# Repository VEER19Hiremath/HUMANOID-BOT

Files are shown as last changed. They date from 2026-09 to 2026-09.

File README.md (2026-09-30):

# HUMANOID-BOT — Hospital Delivery Robot

ROS 2 **Jazzy** workspace for a differential-drive hospital delivery robot: voice room commands, Nav2 navigation, RPLIDAR, and Arduino Mega + matched **BLDC-5015A** wheel drivers (left + right).

Repository: [VEER19Hiremath/HUMANOID-BOT](https://github.com/VEER19Hiremath/HUMANOID-BOT)

> **New here? Read [docs/HANDOVER.md](docs/HANDOVER.md)**: wiring with cable colours, setup (`./setup.sh`), running, calibration, every file explained, troubleshooting. Map of the rooms: [docs/room_map.png](docs/room_map.png).

---

## Hardware

| Part | Notes |
|---|---|
| Raspberry Pi / Ubuntu PC | ROS 2 Jazzy |
| Arduino Mega 2560 | USB to Pi; driver control + wheel-speed feedback |
| BLDC-5015A drivers (×2) | Matched left + right; battery on **DC+/DC−** |
| Brushless hub motors (×2) | Phase U/V/W + Hall plug into each driver |
| Wheel-speed feedback (×2) | One pulse wire per driver into D2/D3 (no separate encoders) |
| RPLIDAR A2M8 | USB (`/dev/lidar` or `ttyUSB0`) |
| Mic + speaker | Voice in / Google TTS out |

Driver switches (both sides):

| Setting | Position |
|---|---|
| **SW2** | **OFF** (speed from Mega AVI, not the knob) |
| **SW1** | Leave as-is (do not change for demo) |
| Round knob **RV** | Fully **counter-clockwise** (min) when using AVI |

Motor battery powers the drivers only (24–50 V on DC+/DC−). **Never** power drivers from Mega 5V. After a latched one-wheel fault: battery **OFF → wait ~10 s → ON**.

Firmware pin map: `arduino/wheelodom.ino`. Cable colors below match the **current robot harness** used in this project.

---

## Wiring (detailed)

Do all control wiring with the **motor battery disconnected**. Connect the battery last.

### 1. Battery → both BLDC-5015A drivers

| Battery | Left driver | Right driver |
|---|---|---|
| + (24–50 V) | **DC+** | **DC+** |
| − | **DC−** | **DC−** |

Check polarity twice. Nothing else on DC+/DC−.

### 2. Motor → driver (each side)

| Motor cable | Driver terminal |
|---|---|
| Three thick phase wires | **U**, **V**, **W** (keep the same order; do not swap for “direction”) |
| Small Hall sensor plug | Hall socket (**REF+**, **REF−**, **HU**, **HV**, **HW**) — push fully in |

Direction is controlled by the Mega **F/R** pin, not by swapping phases.

### 3. Driver control cable → Arduino Mega

Opto commons on the drivers share **+5 V / Vcc** on the driver side; Mega **black** wires are signal **GND** back to the Mega.

| Cable color | Driver signal | Left Mega pin | Right Mega pin | Role |
|---|---|---|---|---|
| **Purple** | **AVI** | **D10** | **D9** | Speed (PWM). Crossed on this harness: left driver ← D10, right ← D9 |
| **Yellow** | **F/R** | **D52** | **D53** | Direction |
| **Red** | **ENBL** | **D22** | **D23** | Run / stop (HIGH = run) |
| **Blue** | **BRK** | **D30** | **D31** | Brake (LOW = released) |
| **Black** | Common / GND | **GND** | **GND** | Signal ground (both drivers) |

> Bench-verified 2026-09-30: **yellow is direction, blue is brake.** An older version of this table had them the other way round. Each wheel then ran one direction only and stalled under PWM in the other, which caused the red driver LED, the "brake stuck" feel and the blown fuses. Always keep **purple → D9/D10** (speed). If purple ever lands on a direction or brake pin, the wheel can run away.

Same table by pin (quick check):

| Mega pin | Goes to |
|---|---|
| D10 | Left AVI (purple) |
| D9 | Right AVI (purple) |
| D52 | Left F/R (yellow) |
| D53 | Right F/R (yellow) |
| D22 | Left ENBL (red) |
| D23 | Right ENBL (red) |
| D30 | Left BRK (blue) |
| D31 | Right BRK (blue) |
| GND | Both driver commons (black) |

### 4. Wheel-speed feedback → Arduino Mega

Each driver's wheel-speed pulse wire goes to the Mega through a **1 kΩ** series resistor. The separate encoders are no longer used (they were never mounted on the wheels). **No 5V** goes to these wires; the Mega's internal pull-up reads them, and the black control wire already shares GND.

| Wire | From | Left Mega pin | Right Mega pin | Role |
|---|---|---|---|---|
| Speed pulse | Driver speed output (or motor Hall line) | **D2** via 1 kΩ | **D3** via 1 kΩ | Wheel pulses (D2/D3 are the only interrupt pins used) |

The firmware uses these pulses for three things:

- **Wheel speed control:** each wheel's speed is measured from the time between its pulses, and a PI loop sets the effort so the wheel turns at the commanded speed whatever its drag. Effort never goes above 32 (the fuse cap).
- **Odometry:** pulses are counted *signed*, in the direction the wheel is driven (a direction change waits until the wheel has coasted down). `base_controller` turns them into `/odom` using the metres-per-pulse in `src/hospital_bringup/config/odometry.yaml`, which it sends to the Mega at connect (`K:<left> <right>`).
- **Stall cut:** a driven wheel that gives no pulse for 0.5 s (after a 1 s start-up grace per wheel) stops both wheels (`STALL HARD STOP`) for a 10 s cool-down, then retries as a fresh start.

`odometry.yaml` holds provisional values until the floor is measured: run `python3 scripts/floor_calibrate.py --tape` once on the floor.

Bench tools (wheels lifted, stack stopped with `./start.sh stop`, Mega auto-detected):

| Script | Purpose |
|---|---|
| `scripts/phase_check.py` | 1.5 s forward + reverse; each wheel must show `OK — runs both ways` |
| `scripts/drive_test.py` | Drives both hubs slowly (3–4 s) with all firmware safeties on; `PASS` needs pulses from both wheels |
| `scripts/bench_matrix.py` | Full BRK / ENBL / F-R / speed case table per wheel (hands off) |
| `scripts/brake_test.py` | Holds raw BRK/ENBL levels (PWM 0) so you can feel which level brakes |
| `scripts/encoder_check.py` | Hand-turn each wheel and read the pulse counts (driver powered) |

### 5. USB / PC

| Device | Port on Pi |
|---|---|
| Arduino Mega | USB → often `/dev/ttyACM0` or `/dev/arduino` |
| RPLIDAR | USB → `/dev/ttyUSB0` or `/dev/lidar` |

Keep Mega and lidar on **separate** USB paths when possible. Motor EMI can drop the Mega (`disabled by hub (EMI?)`) while the lidar keeps spinning.

### 6. Power-up order

1. Mega USB to Pi (sketch boots, `SAFE START READY`, wheels must stay still)  
2. Control + speed-feedback wires as above  
3. Confirm driver LEDs are **off** at idle  
4. Motor battery ON last  
5. `./start.sh`  

### 7. Idle LEDs (healthy)

| Light | Idle expectation |
|---|---|
| Pi / PC power | On |
| Mega ON | Bright |
| Mega TX | May flicker (encoder / status prints) |
| Left / right BLDC LED | **Off** (on = alarm / fault — power-cycle battery) |

Driver manual: [BLDC-5015A / BLDC-5015](https://www.ht-gear.com/uploads/BLDC5015-EN.pdf). Both sides must use the same switch settings (SW2 OFF, RV min).

---

## Quick start

```bash
cd ~/Desktop/veeresh/hospital_robot_ws   # or your clone path
# build once
source /opt/ros/jazzy/setup.bash
colcon build --symlink-install
source install/setup.bash

# run
./start.sh          # base + lidar + map + Nav2 + RViz + voice
./start.sh status
./start.sh stop
```

**Before `./start.sh`:**
1. Mega USB plugged in (`/dev/ttyACM*` or `/dev/arduino`)
2. Lidar USB connected
3. **Place the robot in the MIDDLE of the 30 × 40 ft area, facing along the 40 ft side** (the default map `maps/area_30x40.yaml`; rooms and arrow in `docs/room_map.png`). Its position is counted from that start point, so start it in the same place and direction every time. Scanned maps (`./start.sh map`) use AMCL instead; for those, use RViz **2D Pose Estimate** if the lidar dots don't line up with the walls
4. Prefer **motor battery OFF** until the stack says ready (reduces USB EMI dropouts)
5. Then battery ON to drive

Logs: `run_logs/latest/` in the project, one folder per run (`base.log`, `nav.log`, `voice.log`, …), kept across reboots (newest 30 runs). `/tmp/hospital_robot_logs` points at the latest run. `log/` only holds `colcon build` logs.

### Map a new floor (one command)

The robot only navigates correctly on a map of the floor it is on.

1. Put the robot at the spot that should be **home**, facing the way it will always start (this becomes (0, 0) on the map).
2. Run:
   ```bash
   ./start.sh map
   ```
3. Drive with the keyboard **in the same terminal**: `i` forward, `,` back, `j`/`l` curve left/right, `k` stop. Speed is capped at 0.06 m/s. Go slowly along every wall and into every room. There is **no obstacle stop** while mapping.
4. The map **auto-saves every 30 s** to `maps/floor_map.*`. When it's complete, press **Ctrl+C**. That saves the final map.
5. In RViz pick **Publish Point** and click each spot when the terminal asks: home, room1, room2, … Enter skips a room. This writes `room_config.py` and AMCL's start pose.
6. Everything stops by itself. Put the robot at home and run `./start.sh`. It uses `maps/floor_map.yaml` automatically from now on (`MAP=maps/hospital_map.yaml ./start.sh` for the old lab map).

A previous floor map is kept as `maps/floor_map.bak.*`. To redo only the rooms: run `./start.sh`, then `python3 scripts/pick_rooms.py`.

### Safety while driving

- **Obstacle stop** (lidar, `collision_monitor`): stops for anything 0.27–0.65 m ahead in a 0.60 m wide zone, and drives at 70 % speed for 0.65–1.10 m ahead. `start.sh` prints `Obstacle stop: OK`. If it isn't active, the robot does not drive at all.
- **Microphone watchdog**: **off by default**. In a quiet room a live headset reads the same as a dead one (rms 1–3), so it stopped every trip. `mic_watchdog_s:=15.0` on the voice node turns it on. Because a dead headset can go unnoticed, keep the battery switch or `./start.sh stop` within reach.
- Always keep the motor battery switch, or `./start.sh stop`, within reach.

### Voice examples

After it says listening:

- `go to room one` / `room two` / `room three`. Say numbers as words: the speech model has no digits
- `go home` / `reception`

Speech uses **Google TTS** (needs network); falls back to `espeak` if offline.

---

## Packages (`src/`)

| Package | Role |
|---|---|
| `hospital_bringup` | `real_robot.launch.py`, Nav2 params, localization |
| `hospital_delivery` | Voice delivery node, RViz config, rooms |
| `hospital_description` | URDF / meshes |
| `hospital_world` | Gazebo world (sim) |
| `wheel_odometry` | `base_controller` (Arduino + odom) |
| `rplidar_ros` / `sllidar_ros2` | Lidar drivers |

Demo defaults in `start.sh`:

- `odom_source:=command` (commanded speeds → odom; encoders optional)
- `idle_close_s:=5.0` (closes Arduino serial when parked — less EMI)
- Static `map` → `odom` at start pose `(2.2, 1.6)`
- Lidar obstacle layers disabled in `nav2_params.yaml` when the hospital map ≠ current room (re-enable after remapping)

---

## Arduino firmware

```bash
# Flash Mega (example)
arduino-cli compile -b arduino:avr:mega arduino/wheelodom
arduino-cli upload -b arduino:avr:mega -p /dev/ttyACM0 arduino/wheelodom
```

Sketch: `arduino/wheelodom.ino`. Host tests (simulated wheels with drag, stalls, reversals, timeouts): `arduino/test/run_tests.sh`.

Test tools (stack running, wheels lifted or a clear floor):

| Script | What it checks |
|---|---|
| `scripts/wheel_speed_test.py` | Commanded vs measured speed: straight, slow, arcs, reverse, direction change, stop time |
| `scripts/e2e_test.py [N]` | N random trials through the whole chain (voice command → Nav2 → base → Mega): trips, stop mid-trip, redirects, noise phrases. Results in `run_logs/latest/e2e_results.json` |
| `scripts/plan_check.py` | Plans every room pair (no driving): length, reverses, turn radius, wall clearance |
| `scripts/floor_calibrate.py --tape` | Floor calibration of metres per pulse (drives 1.5 m after Enter) |

Type a command instead of speaking: `ros2 topic pub --once /voice_command std_msgs/String "data: go to room one"`.

---

## Build notes

- Ignore `build/`, `install/`, `log/` (see `.gitignore`)
- Optional: `~/venv` for voice deps; system needs `gTTS`, `vosk`, `sounddevice`, `ffplay` or `mpg123`
- Udev helpers often symlink Mega → `/dev/arduino`, lidar → `/dev/lidar`

---

## Known issues (demo)

| Symptom | Cause | What is in place / what to do |
|---|---|---|
| Wheels fight each other, chassis spins in place | Hubs face opposite ways; same F/R polarity on both sides | Firmware `LEFT_INVERTED=true`, `RIGHT_INVERTED=false`. Opposite-sign wheel commands are blocked in firmware. |
| Fuse blows | A hub stalled under PWM (one direction never ran, see the F/R row below) or a jammed wheel | Fixed root cause (F/R and BRK pins). Also: PWM capped at 30–32, slow ramp up, 300 ms command timeout, opposite-sign commands blocked, `TEST` disabled, and the **stall cut** stops both wheels within ~0.5 s if a wheel gives no speed pulses. Keep one correctly rated fuse per driver. |
| `STALL HARD STOP` in `logs/base.log`, bot stops for 10 s | A wheel gave no speed pulses for 0.5 s while driven: jammed wheel, driver fault (red LED), or a loose D2/D3 feedback wire | Clear the jam, power-cycle the battery if the LED is red, check the feedback wire, then run `scripts/drive_test.py` (wheels lifted). |
| `ENC RIGHT SUSPECT` (or `LEFT`) warning | Only with `ENC_SUSPECT_BYPASS = true`: one feedback line frozen while the other counts | Default is `false` (any frozen wheel = hard stop, which protects the fuses). Turn it on only to keep driving with a known-bad feedback wire. |
| Robot drives in circles; turns go the wrong way | The two **purple speed wires are crossed**: D9 drives the D23/D31/D3 driver and D10 the D22/D30/D2 one (bench 2026-09-30, one wheel at a time). "Slow the left wheel to turn left" slowed the right one, so every turn was reversed. On the floor this looked like an inverted speed signal; with the wheels lifted it's normal (a higher byte is faster) | Fixed in firmware: `L_AVI` = D10, `R_AVI` = D9. `arduino/test/run_tests.sh` checks the pin map. Different drag/speed per wheel is now handled by the firmware's wheel speed control. |
| Robot drives for minutes and never arrives | The floor isn't the mapped room (the map is the 40 × 28 ft lab; the test floor is ~18 ft) | Map the floor you drive on (see **Map a new floor**). |
| Robot doesn't stop or slow for people or objects | Collision monitor and costmap obstacle layers were all disabled | Fixed: `start.sh` runs the collision monitor (see **Safety while driving**). |
| `stop` not heard while driving | The headset mic went silent after the robot spoke (flat signal in `hfp.log`) | The microphone watchdog now stops the robot. Keep the headset close; if it happens, power-cycle the headset link. |
| Robot leaves the map in RViz, or drives somewhere other than where Nav2 thinks | AMCL was disabled. The pose came only from commanded speeds, pinned to a fixed map→odom, so the drift was never corrected | Fixed: `localization.launch.py` runs AMCL (lidar localization), and `start.sh` passes `static_map_odom:=false`. Start the robot at home, or set **2D Pose Estimate** in RViz. |
| Says "Arrived" but the robot is somewhere else (or still stuck near the start) | Pose came from **commanded** speeds (`open_loop_odom`). Log 2026-09-30: the robot stalled 9 s into a trip, the Mega cut drive 9 times, but the pose kept advancing and Nav2 "reached" room1 99 s later | Fixed: odometry comes only from the wheels' signed pulse counts (the command-based mode is removed). A stuck robot fails the goal instead of faking arrival. Calibrate metres per pulse once on the floor (`scripts/floor_calibrate.py --tape`). |
| Nav2 running but bot never moves; `/cmd_vel_nav` has no subscribers | `velocity_smoother` not activated | `velocity_smoother` is in the lifecycle list of `navigation.launch.py`. Check with `ros2 lifecycle get /velocity_smoother`. |
| Goals abort with `Failed to create plan` | The goal or the robot sits inside a wall's inflation | Planner `tolerance: 0.25`. Keep room goals at least 0.6 m from walls in `room_config.py`, then run `scripts/plan_check.py` (plans every room pair without moving the wheels). |
| Path cuts across a wall end in RViz; robot gets stuck in a small room it can't turn around in | Navfn drew sharp corners the arcs-only base can't drive (tightest radius ~0.54 m in `base_controller`); the robot swung wide. And since composition, the **costmaps ignored `nav2_params.yaml`** (Nav2 defaults: 0.1 m radius, no footprint), because the container itself wasn't given the file | Fixed: **Smac Hybrid-A\*** planner (`minimum_turning_radius: 0.60`, Reeds-Shepp = short reverse legs like a 3-point turn), RPP `allow_reversing: true`, the real body footprint 0.54 × 0.50 m, inflation 0.60 m, the params file passed to the container. Goals point along the line from the robot to the room (`goal_yaw`). `scripts/plan_check.py`: 30/30 paths inside the area, body ≥ 0.07 m from every drawn wall. |
| Robot stops for no reason; `collision_monitor: Robot to stop due to invalid source` | On a loaded Pi the odometry TF ran 1–2 s late, so matching each scan to the pose at its exact time failed and the obstacle stop held the robot | `base_shift_correction: false` (uses the latest pose; < 0.1 m error at 0.06 m/s) and replanning every 3 s instead of every 1 s. Close extra programs (browser, VS Code) on the Pi while driving. |
| Robot drives off to room 1 or room 2 by itself | Vosk turned background talk / motor noise into bare words (`one`, `the one`, `a one`, `two`); each was taken as a command (6 times in 10 min on the bench) | Fixed: a room needs a full phrase (`room one`, `go to room one`, `go to the one`, `take me to room four`, `go home`, `reception`). Bare numbers are logged as `Ignoring short phrase` and ignored. `stop` alone still works. |
| `start.sh` hangs during bringup | Lifecycle/DDS calls (map, collision monitor, `/scan`) block | Every check is wrapped in `timeout 2` and only prints a warning. |
| One wheel on straight / both on turn, red LED on driver | Driver latch, F/R, or current brownout | `motorEnable()` toggles ENBL stop→run to clear the latch, and stopping coasts instead of braking. If the red LED stays on, power-cycle the motor battery. |
| Forward: only left turns. Reverse: only right turns. Wheel "tries but can't", red driver LED, fuses blow | Firmware drove the blue wire as direction and the yellow wire as brake, but on the drivers it's the other way round. So each hub ran one way only and stalled under PWM the other way | Fixed in firmware: F/R is on D52/D53 (yellow) and BRK on D30/D31 (blue). `scripts/phase_check.py` must show both wheels `OK — runs both ways`. |
| `start.sh` prints `Obstacle stop: PROBLEM (unconfigured)` and the robot never drives | One of ~10 separate Nav2 processes hung while joining DDS at startup (a different one each time), so Nav2's lifecycle manager waited forever (bench 2026-09-30: 3 of 3 starts) | Fixed: Nav2 runs **composed** (all servers in one `component_container_isolated`, `use_composition:=true`, as in Nav2's own bringup): 4 of 4 starts were healthy. `start.sh` also restarts once if the health check fails, and `stop` cleans stale Fast DDS shared memory (`fastdds shm clean`). |
| Robot swings wide in turns and cuts through walls in RViz / leaves the area | The slowest speed the firmware used (PWM 22) still ran a wheel at ~70 % of cruise, so the inner wheel couldn't slow down: the tightest arc was ~1.5 m wide. The controller's collision check was off, and the `base_controller` map clamp froze the pose at its rectangle edge (goal timeouts) | Fixed: speed maps to effort **in proportion** (`PWM_ZERO_SPEED` 5, cruise 30, min 10; lifted bench: 6 → 9/s … 30 → 56/s), so turn ratios are real. RPP `use_collision_detection: true` stops before a mapped wall. The clamp only applies to open-loop odometry. |
| On the floor: `STALL HARD STOP` every 10 s and the robot never moves again | After a stall's 10 s cool-down the firmware restarted with the **old** motion-start time and stall timers: no start grace, no breakaway kick, and the PWM is up within a millisecond. A loaded wheel that needed a moment to start re-faulted 40 ms later, forever (floor log 2026-09-30) | Fixed: a fault and its cool-down reset `motion_start_ms`, so every retry is a fresh start. Start grace 1000 ms, breakaway 300 ms (was 400 / 150). Obstacle slow zone 70 % speed (50 % = 0.03 m/s was too little effort on the floor). Test: `arduino/test/run_tests.sh`. |
| Tight turns stall every 10 s (`stall/fault` in `base.log`) | Inner-wheel commands of 0.01–0.02 m/s got PWM 0 while still counting as "moving" | Fixed: a moving wheel always gets at least `PWM_START`. |
| Robot detours, loops or reverses "randomly" on the test floor | It planned around the drawn 30 × 40 ft walls, which don't exist on the 18 ft floor | `start.sh` now defaults to **`maps/open_floor.yaml`** (20 × 20 ft test area, no interior walls; rooms 1.3–1.6 m from home, leaving room for forward-only turn-arounds). Rooms are listed in each map (`# room:` lines) and the voice node uses the loaded map's rooms. `MAP=maps/area_30x40.yaml ./start.sh` for the walled area; other floor sizes: `python3 scripts/make_area_map.py open_floor --size W H`. |
| Robot drives in circles / curves although RViz shows a straight path | Odometry scales are provisional: if one wheel's pulses are "shorter", odometry sees a turn that isn't there and Nav2 steers against it | Calibrate once on the floor: `python3 scripts/floor_calibrate.py --tape` (drives 1.5 m after you press Enter, asks for the measured forward/sideways distance, writes `config/odometry.yaml`). |
| Robot ignores things straight ahead; stops for things beside it | The lidar sits inside the body: only ~20 % of beams return and almost none from −40° to +40° (straight ahead). Its open views are behind, the front corners (±45–60°) and the left | No software fix: the obstacle stop **cannot see straight ahead**. Stay at the battery switch. `start.sh` prints `Lidar view: WARNING` while this is so. An opening in the body ahead of the lidar (or mounting it on top) fixes it. The stop zone also watches **behind** the robot while it reverses. |
| Robot sets off or changes destination by itself | Vosk turned noise into phrases like `[unk] gotta toronto` or a bare `toronto` | Phrases with unrecognised sound (`[unk]`) never send or redirect the robot; `toronto` only counts as `go to toronto`. `stop` always works. |
| `stop` acted on ~20 s late, or not at all | The recognizer fell ~20 s behind the headset audio while the Pi was busy driving | It never lags more than ~1 s now (older audio is dropped, logged as `behind: dropped`); cheaper mic level maths; RViz runs at low priority. |
| Robot curves / circles; travels further than the goal; "forgets where to go" | The firmware set a fixed effort per speed, so a wheel with more drag turned slower and the robot curved; the base controller also added guessed motion between pulse reports (double counting) and had several half-wired odometry modes | Rewritten end to end: closed-loop wheel speed in the firmware, pulse-only signed odometry in `base_controller`. Bench: speeds within 3 % of the command, stop in 0.65 s; 100/100 end-to-end trials. |
| `stop` ignored now and then | "stop" cancelled the goal through its handle, which is missing when Nav2's "accepted" reply is lost | "stop" now cancels **all** Nav2 goals (no handle needed), acts the moment it's heard, and zeroes the wheels. 25/25 stop trials: wheels still in ≤ 0.8 s. |
| Robot stops ~0.3 m short of a room | Goal tolerance was 0.30 m | `xy_goal_tolerance: 0.15`: 100 trials arrived within 0.18 m (odometry). |
| Robot spins on the spot ("tornado"), says "Arrived" somewhere else | Wheel DIRECTION CHANGES: the left driver doesn't reliably follow an F/R change made soon after running, so after a reverse leg one wheel kept going backwards. The pulses carry no direction, so odometry saw normal driving | Navigation is **forward-only** (Smac DUBIN planner, no BackUp recovery, no reverse speed), and the firmware switches a driver off while its direction changes (re-key). Direction settings stay `LEFT_INVERTED true`, `RIGHT_INVERTED false` (a straight run from rest goes straight). |
| Robot drives much further and faster than told, crosses the boundary | The drivers give only ~12-13 speed pulses per wheel turn; the guessed 2.5 mm per pulse was ~15x too small | **Measured on the floor (tape at both wheels): 36 mm per pulse, right 0.92 of left** (`config/odometry.yaml`). Cruise 0.15 m/s (real). Re-measure after any wheel, driver or wiring change. Counting both pulse edges was tried and dropped: the right signal adds false edges. |
| Robot creeps into a wall in short stop/go steps | The collision monitor alone sees the few lidar points ahead appear and vanish: each 'continue' let it creep forward | Both costmaps now have a lidar **obstacle layer**: walls and objects stay marked until the lidar sees through them, the planner routes around them and the controller stops before them. |
| "go home" heard as just "home" (ignored) | The mic gate fed the recognizer only audio above the noise floor: the soft start of a phrase and the gaps between words were cut | The last 0.5 s before speech is fed with it, and audio keeps flowing 0.8 s after it. |
| Only one particular headset worked | `hfp_mic.py` had the AirPods' address built in and handled only the mSBC codec | Any paired hands-free headset (connected first, then the others) with mSBC or CVSD; without one, the system mic (USB / wired). New headset: pair it once (`bluetoothctl`: `pair`, `trust`, `connect`). |
| A wheel stalls on slow turns / at the start on the floor | Floor friction stops a slow inner wheel; the PI loop was too slow to free it | Stuck-wheel **kick** (breakaway effort 24 for up to 0.4 s when pulses are missed); start-up push until the first pulse; stall cut waits for 3 pulse gaps. |
| Robot curves on straight lines | Different drag per wheel; small speed differences add up | Per-wheel speed control **plus wheel synchronisation**: the real distances of the two wheels are kept at the commanded ratio (sim: 1 count apart vs 21 without). |
| One wheel gives 0 pulses / won't move (bench test) | Driver latched (red LED) | Battery off 10 s, then on. `scripts/direction_level_test.py` / `brake_level_test.py` test each wheel alone. |
| Mega USB disappears | Motor EMI (`disabled by hub (EMI?)`) | Turn the battery off, reseat the Mega on another USB port, then run `./start.sh` (the script waits up to 90 s for the device). |

Lidar can spin while Mega is missing — they are separate USB devices; start still requires the Arduino.

---

## License

Package licenses are declared in each package’s `package.xml` (mostly Apache-2.0 where specified). Third-party lidar SDK code retains upstream licenses.

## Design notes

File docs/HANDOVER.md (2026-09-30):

# Hospital Delivery Robot — Handover

This document is everything needed to wire, set up, run, calibrate, change and debug the robot. It describes the version on branch **`floor-tested-v1`** (October 2026), which was tested on a 20 × 20 ft open floor.

- Repository: <https://github.com/VEER19Hiremath/HUMANOID-BOT>
- Quick reference and fix history: [`README.md`](../README.md)

---

## Contents

1. [What the robot does](#1-what-the-robot-does)
2. [How it fits together](#2-how-it-fits-together)
3. [Hardware](#3-hardware)
4. [Wiring, with cable colours](#4-wiring-with-cable-colours)
5. [Setting up a computer](#5-setting-up-a-computer)
6. [Running the robot](#6-running-the-robot)
7. [The map and the rooms (RViz)](#7-the-map-and-the-rooms-rviz)
8. [Calibration](#8-calibration)
9. [The code, file by file](#9-the-code-file-by-file)
10. [Tests and test tools](#10-tests-and-test-tools)
11. [Troubleshooting](#11-troubleshooting)
12. [Known limits and next steps](#12-known-limits-and-next-steps)

---

## 1. What the robot does

You say a room ("go to room two") into a Bluetooth headset or a USB microphone. The robot plans a route and drives there on its two hub-motor wheels. It stops at once when you say **"stop"**.

On the way, it stops for people and objects the lidar sees, drives around them when there is room, and waits for them to move when there isn't.

What works (tested on the floor):

- **Voice.** Room commands; "go home"; instant "stop"; redirecting to a new room mid-trip; noise and half-heard phrases are ignored.
- **Driving.** Closed-loop wheel speeds, synchronised wheels, measured odometry, forward-only arcs, stall protection.
- **Navigation.** Rooms 1–3 and home on a 20 × 20 ft map, about 1.2–1.3 m from the centre.
- **Obstacles.** Detour at a safe distance, or wait and continue.

Limits are listed in [section 12](#12-known-limits-and-next-steps). The most important: the robot knows its position **only from its wheels**. On an empty floor the lidar has nothing to localise against, so expect about ±10–25 cm at a room.

---

## 2. How it fits together

```mermaid
flowchart LR
    MIC["Headset / USB mic"] --> HFP["hfp_mic.py<br/>(Bluetooth bridge)"]
    MIC --> PW["PipeWire<br/>(USB / wired mic)"]
    HFP --> VOICE["voice_delivery_node<br/>(Vosk speech → room)"]
    PW --> VOICE
    TXT["/voice_command<br/>(typed commands)"] --> VOICE
    VOICE -- "NavigateToPose goal" --> NAV["Nav2<br/>planner + controller"]
    LIDAR["RPLIDAR A2M8"] -- /scan --> NAV
    LIDAR -- /scan --> CM["collision_monitor<br/>(obstacle stop)"]
    NAV -- /cmd_vel_smoothed --> CM
    CM -- /cmd_vel --> BASE["base_controller<br/>(wheel speeds, odometry)"]
    BASE -- "USB serial: VL/VR, K" --> MEGA["Arduino Mega<br/>wheelodom.ino"]
    MEGA -- "speed, F/R, ENBL, BRK" --> DRV["2 × BLDC-5015A drivers"]
    DRV --> MOT["2 × hub motors"]
    DRV -- "speed pulses D2/D3" --> MEGA
    MEGA -- "pulse counts L:/R:" --> BASE
    BASE -- "/odom + TF" --> NAV
    NAV --> RVIZ["RViz<br/>(map, rooms, path)"]
```

In words:

1. **Speech to goal.** `voice_delivery_node` turns a recognised phrase into a room. It sends Nav2 a goal at that room's position, taken from the map file.
2. **Planning.** Nav2's planner (Smac Hybrid-A\*, forward-only) plans a route made of arcs the robot can actually drive.
3. **Following.** The controller (Regulated Pure Pursuit) follows that route and outputs a body speed and turn rate.
4. **Safety gate.** The collision monitor passes those commands on, or replaces them with a stop or a slowdown when the lidar sees something close ahead.
5. **Wheel speeds.** `base_controller` turns body speed and turn rate into left and right wheel speeds. It sends them to the Mega 50 times a second.
6. **Motor control.** The Mega runs a speed controller for each wheel. It sets each driver's speed input (PWM), direction, enable and brake, using the wheel-speed pulses from the drivers.
7. **Odometry.** The Mega reports pulse counts every 50 ms. `base_controller` turns them into the robot's position (`/odom` and the `odom → base_footprint` transform).
8. **Map frame.** With the drawn map, `map → odom` is fixed at the start spot ("home"). The robot's position is therefore pure wheel odometry from where it was started.

---

## 3. Hardware

| Part | Notes |
|---|---|
| Raspberry Pi (Ubuntu 24.04, ROS 2 Jazzy) | Runs everything except motor control |
| Arduino Mega 2560 | USB to the Pi; motor drivers and wheel-speed feedback |
| 2 × BLDC-5015A motor drivers | Left and right; powered from the motor battery on **DC+ / DC−** |
| 2 × brushless 6-inch hub motors | Three phase wires and a Hall-sensor plug into each driver |
| RPLIDAR A2M8 | USB; 360° at 10 Hz, range 12 m |
| Bluetooth headset or USB microphone | Voice input; any paired hands-free headset works |
| Motor battery (24–50 V) | Drivers only, with one fuse per driver |
| Robot body | **2 ft × 1.5 ft** (0.61 × 0.46 m), centred on the wheel axle; wheels 0.43 m apart |

Driver switches, the same on **both** drivers:

| Setting | Position |
|---|---|
| **SW2** | **OFF**: speed comes from the Mega (AVI input), not the knob |
| **SW1** | Leave as it is |
| Round knob **RV** | Fully **anticlockwise** |

Driver manual: [BLDC-5015A](https://www.ht-gear.com/uploads/BLDC5015-EN.pdf).

---

## 4. Wiring, with cable colours

> **Do all control wiring with the motor battery disconnected. Connect the battery last.** Never power the drivers from the Mega's 5 V.

### 4.1 Battery → drivers

| Battery | Left driver | Right driver |
|---|---|---|
| + (24–50 V), through a fuse | **DC+** | **DC+** |
| − | **DC−** | **DC−** |

Check polarity twice.

### 4.2 Motor → driver (each side)

| Motor cable | Driver terminal |
|---|---|
| Three thick phase wires | **U, V, W**: keep the original order. Do **not** swap them to change direction; the Mega's F/R line does that. |
| Small Hall-sensor plug | Hall socket (REF+, REF−, HU, HV, HW), pushed fully in |

### 4.3 Driver control cable → Mega

| Cable colour | Driver signal | **Left** → Mega | **Right** → Mega | What it does |
|---|---|---|---|---|
| 🟣 **Purple** | AVI | **D10** | **D9** | Speed (PWM). The two purple wires are **crossed** on this harness: the left driver is on D10, the right on D9. |
| 🟡 **Yellow** | F/R | **D52** | **D53** | Direction |
| 🔴 **Red** | ENBL | **D22** | **D23** | Run / stop (HIGH = run) |
| 🔵 **Blue** | BRK | **D30** | **D31** | Brake (LOW = released) |
| ⚫ **Black** | COM / GND | **GND** | **GND** | Signal ground, shared by both drivers |

By pin, for a quick check:

| Mega pin | Goes to |
|---|---|
| D2 | Left speed pulse (through 1 kΩ) |
| D3 | Right speed pulse (through 1 kΩ) |
| D9 | Right AVI (purple) |
| D10 | Left AVI (purple) |
| D22 / D23 | Left / right ENBL (red) |
| D30 / D31 | Left / right BRK (blue) |
| D52 / D53 | Left / right F/R (yellow) |
| GND | Both driver commons (black) |

> **Yellow is direction, blue is brake.** With them the other way round, each wheel ran in one direction only and stalled in the other: red driver LED, blown fuses. **Purple must only ever go to D9 / D10.** A speed wire on a direction or brake pin can make a wheel run away.

### 4.4 Wheel-speed feedback → Mega

| Wire | From | Left | Right |
|---|---|---|---|
| Speed pulse | Driver speed output | **D2** through **1 kΩ** | **D3** through **1 kΩ** |

- No 5 V goes on these wires: the Mega's internal pull-up reads them, and the black wire provides the shared ground.
- The drivers give about **12–13 pulses per wheel turn**, which is **36 mm of travel per pulse**.
- Keep these wires away from the motor phase wires. The **right** signal picks up false pulses (see [section 12](#12-known-limits-and-next-steps)).

### 4.5 USB

| Device | Port |
|---|---|
| Arduino Mega | `/dev/serial/by-id/usb-Arduino*` (found automatically) |
| RPLIDAR | `/dev/serial/by-id/usb-Silicon_Labs*` (found automatically) |

Use separate USB ports. Motor noise can disconnect the Mega; if so, power off, then reseat it on another port.

### 4.6 Power-up order and healthy lights

1. Mega USB to the Pi. It prints `SAFE START READY` and the wheels stay still.
2. Control and speed wires connected.
3. Driver LEDs are **off** at idle.
4. Motor battery **on**.
5. `./start.sh`.

**A red driver LED means the driver has latched a fault.** Turn the battery **off, wait 10 s, turn it on again**.

---

## 5. Setting up a computer

On a fresh Raspberry Pi with Ubuntu 24.04:

```bash
git clone https://github.com/VEER19Hiremath/HUMANOID-BOT.git ~/Desktop/veeresh
cd ~/Desktop/veeresh
git checkout floor-tested-v1
./setup.sh --test          # install everything, build, run the unit tests
./setup.sh --flash         # with the Mega plugged in: put the firmware on it
```

[`setup.sh`](../setup.sh) does the following (each step is skipped if already done):

| Step | What |
|---|---|
| 1 | ROS 2 Jazzy (if missing) and the ROS packages the robot uses: Nav2, the Smac planner, collision monitor, slam_toolbox, robot_state_publisher, teleop, RViz |
| 2 | System packages: pyserial, numpy, scipy, matplotlib; PipeWire, ALSA, BlueZ and the SBC codec (headset audio) |
| 3 | `~/venv` with the speech packages from [`requirements.txt`](../requirements.txt) (Vosk) |
| 4 | The Vosk speech model in `~/models/vosk-model-small-en-us-0.15` |
| 5 | `arduino-cli` and the AVR core in `.tools/` (used to flash the Mega) |
| 6 | Adds you to the `dialout` group for serial-port access. Log out and back in once afterwards. |
| 7 | `colcon build` of the workspace |

### Headset (once per headset)

```bash
bluetoothctl
  scan on              # put the headset in pairing mode; note its address
  pair  XX:XX:XX:XX:XX:XX
  trust XX:XX:XX:XX:XX:XX
  connect XX:XX:XX:XX:XX:XX
  exit
```

After pairing once, the robot picks the headset up by itself. It takes the connected headset first, then tries every paired hands-free headset. A USB microphone also works, with nothing to configure.

**Headsets connect to one device at a time.** Turn off Bluetooth on your phone before starting the robot.

---

## 6. Running the robot

### Start

1. Put the robot **in the middle of the area**, facing the direction you want "forward" (room1 is straight ahead).
2. Battery on.
3. Run:

```bash
cd ~/Desktop/veeresh
./start.sh
```

Wait about 2 minutes for this:

```text
Mega: OK
Lidar:          OK  (10 scans/s)
Odometry:       OK  (20 msgs/s)
Localization:   OK  (map frame published)
Map:            OK  (received)
Obstacle stop:  OK  (active)
Lidar view:     NOTE (… % of beams return …)   ← normal on an open floor
Ready: say 'go to room one' (rooms of the map: see docs/room_map.png), 'go home' or 'stop'.
```

If a check says PROBLEM, `start.sh` restarts everything once by itself. If it still fails: `./start.sh stop`, then `./start.sh` again.

**The spot where you start is "home".** The robot's position is measured from there, so always start at the same place, facing the same way.

### Voice commands

| Say | Robot |
|---|---|
| "go to room one" / "room one" / "go to one" | Drives to room1 (same pattern for two and three) |
| "go home" / "go to home" / "reception" | Drives back to the start spot |
| "stop" | Stops at once and cancels the trip |
| A new room during a trip | Changes destination |

- Speak close to the mic, and use full phrases.
- A bare "one" or "home" is ignored on purpose: background noise produces those.
- Unsure recognitions are logged as `Ignoring unsure phrase …` and do nothing.
- The Pi has no speaker, so the robot doesn't talk back. Its replies ("Going to room 2", "Arrived") appear in the voice log. Plug in a speaker and they're spoken, if Google TTS is installed.

**Typed commands** go through exactly the same path as speech:

```bash
source /opt/ros/jazzy/setup.bash
ros2 topic pub --once /voice_command std_msgs/String "data: go to room two"
```

### Obstacles

| Situation | Behaviour |
|---|---|
| Something 0.70–1.10 m ahead | Slows to 70 % |
| Something 0.32–0.70 m ahead (0.32–0.65 m behind when reversing) | Stops |
| A way round exists | Replans around it, keeping a safe distance (0.6 m inflation), and continues |
| No way round | Waits; tries again every few seconds for about 2–3 minutes, then gives up ("Could not reach") |
| Obstacle goes away | Continues to the room by itself |

### Stop and logs

```bash
./start.sh stop           # stop everything
./start.sh status         # what is running
```

**Emergency stop:** say "stop", or switch the motor battery off.

Every start writes a new log folder: `run_logs/<date>_<time>_start/`. `run_logs/latest` always points at the newest; the last 30 runs are kept.

| Log | Contains |
|---|---|
| `voice.log` | What was heard, what was ignored and why, goals sent, arrivals |
| `nav.log` | Nav2: plans, obstacle stops, failures |
| `base.log` | Mega status every second (effort, pulses, measured and target speed), stalls; lidar driver |
| `hfp.log` | Bluetooth headset bridge |
| `map.log` | Map server |

---

## 7. The map and the rooms (RViz)

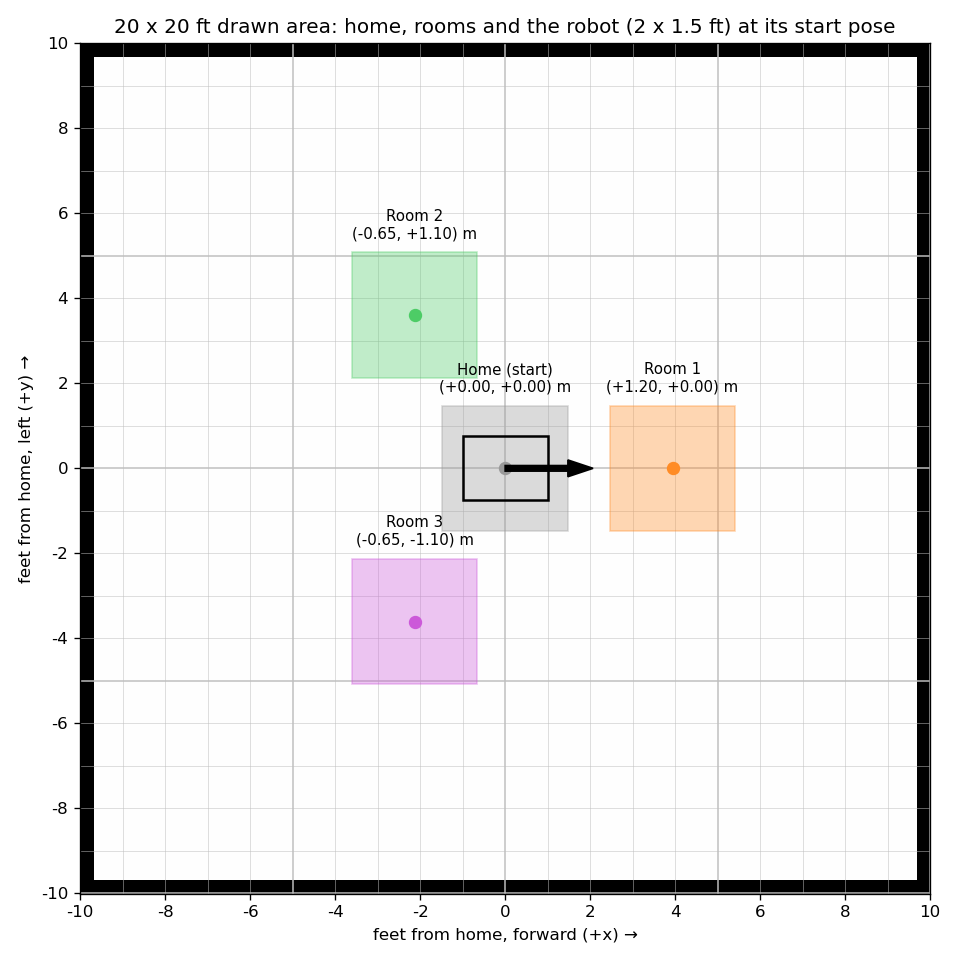
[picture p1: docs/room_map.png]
Map with home and rooms


The current map is **`maps/open_floor.yaml`**: a 20 × 20 ft empty square, with home in the middle.

| Room | Position (x forward, y left), from home | Where |
|---|---|---|
| home | (0, 0) | Start spot, facing +x |
| room1 | (1.20, 0.00) m, about 4 ft | Straight ahead |
| room2 | (−0.65, +1.10) m | Behind, left |
| room3 | (−0.65, −1.10) m | Behind, right |

**What RViz shows** (it opens with `./start.sh`):

- the map;
- coloured **room zones with names** (the room being driven to is highlighted);
- the **planned path** in green;
- the **obstacle-stop zone** in red;
- lidar points;
- the robot model.

**Why the rooms are so close in.** The robot drives forward only, and turns with a radius of at least 0.5 m. To turn round it needs about 1.5 m of floor beyond a room. Rooms further out sent the robot within 0.5 m of an edge, where it got stuck.

### Changing the rooms or the area

1. Edit `MAPS['open_floor']` in [`scripts/make_area_map.py`](../scripts/make_area_map.py): `size_ft` and `rooms` (in metres, x forward, y left).
2. Regenerate the map, the picture, and check every trip without driving:

```bash
python3 scripts/make_area_map.py open_floor     # writes maps/open_floor.pgm/.yaml
python3 scripts/render_map.py                   # writes docs/room_map.png
./start.sh                                      # then, in another terminal:
python3 scripts/plan_check.py                   # plans every room pair (no driving)
```

`plan_check.py` must report `0 problem path(s)`. Each path's `wall gap` should be 0.4 m or more.

The rooms live **in the map file** as `# room: name x y` lines. The voice node and RViz both read them from there. `room_config.py` only holds the spoken names and a fallback.

### Scanning a real room instead (optional)

In a room with walls and furniture, a scanned map lets the lidar correct the position continuously. That is more accurate than wheel odometry alone.

```bash
./start.sh map
```

Drive slowly along every wall with the keyboard. The map auto-saves every 30 s. Press Ctrl+C when done, then click the rooms in RViz when asked.

`start.sh` then uses `maps/floor_map.yaml` with lidar localisation (AMCL). This is **not useful on an empty floor**: there is nothing for the lidar to see.

---

## 8. Calibration

### Wheel distance (do it after changing a wheel, driver or wiring)

The robot's sense of distance comes from `src/hospital_bringup/config/odometry.yaml`:

```yaml
distance_per_pulse: 0.0360        # metres per LEFT wheel pulse
right_encoder_multiplier: 0.92    # right pulse length / left
```

To re-measure:

1. `./start.sh`, with about 2 m clear ahead.
2. In a second terminal, run `./start.sh calibrate`.
3. Tape the floor at both wheel hubs and press Enter. The robot drives 1.5 m (by its own count).
4. Tape the hubs again. Type how far the midpoint moved **forward** and **sideways** (cm, left is +).
5. It writes the new values. Run `./start.sh stop; ./start.sh`.

By hand instead: drive 1 m by its count, measure **each wheel's** travel, and set:

- `distance_per_pulse = (left wheel cm / 100) / left pulses`;
- `right_encoder_multiplier = (right cm / left cm) × (left pulses / right pulses)`.

The pulse counts are in `base.log` (`L=… R=…`).

### Wheel direction (after any motor or driver rewiring)

```bash
./start.sh stop
python3 scripts/wheel_direction_test.py     # each wheel alone at its forward level (read from the firmware), 3 s
```

**Each wheel must roll forward.** If one rolls backward, flip `LEFT_INVERTED` or `RIGHT_INVERTED` in `arduino/wheelodom.ino` and reflash (`./setup.sh --flash`).

Current, verified setting: `LEFT_INVERTED true`, `RIGHT_INVERTED false`. A straight run from rest must go straight.

---

## 9. The code, file by file

### 9.1 Overview

| Path | Language | Role |
|---|---|---|
| `arduino/wheelodom.ino` | Arduino C++ | Motor control on the Mega |
| `arduino/test/` | C++ | Host tests for the firmware (simulated wheels) |
| `src/wheel_odometry/` | Python (ROS 2) | `base_controller`: Mega link, wheel speeds, odometry |
| `src/hospital_delivery/` | Python (ROS 2) | Voice control, rooms, RViz room markers, RViz config |
| `src/hospital_bringup/` | Launch / YAML | Starting everything, Nav2 settings, odometry calibration, behaviour tree |
| `src/hospital_description/` | URDF | Robot model (frames: base_footprint, base_link, laser, wheels) |
| `src/rplidar_ros/` | C++ | Lidar driver (vendor package, with startup fallbacks added) |
| `src/hospital_world/`, `src/sllidar_ros2/` | | Simulation world and a spare lidar driver. **Not used** on the real robot. |
| `maps/` | | `open_floor` (current), `area_30x40` (old drawn area); a scan becomes `floor_map` |
| `scripts/` | Python | Setup helpers, calibration, tests, map tools |
| `start.sh`, `setup.sh` | Bash | Run the robot / install everything |

### 9.2 `arduino/wheelodom.ino`: motor control on the Mega

Runs on its own, independent of ROS. If the Pi stops talking for 300 ms, the motors stop.

**Serial protocol (115200 baud):**

| Pi → Mega | Meaning |
|---|---|
| `VL:<m/s> VR:<m/s>` | Wheel speeds. Must repeat within 300 ms. |
| `K:<left> <right>` | Metres per pulse for each wheel. Sent by `base_controller` at connect. |
| `PINS …` / `PINS OFF` | Bench mode: raw pin levels on one wheel. Stops by itself 1.5 s after the last command. |

| Mega → Pi | Meaning |
|---|---|
| `SAFE START READY` | Booted, motors off |
| `L:<count> R:<count>` | Signed pulse counts, every 50 ms |
| `S: pwmL=… pwmR=… … spL=… spR=… tgL=… tgR=…` | While driving: effort, measured (`sp`) and target (`tg`) wheel speed in pulses/s |
| `STALL HARD STOP` | A driven wheel stopped turning; both cut for 10 s |
| `K OK <l> <r>` | Pulse sizes accepted |

**How it drives a wheel** (`controlWheel()`, every 20 ms):

- **Speed measurement.** Each speed pulse fires an interrupt (`countPulse`). The interrupt counts the pulse (signed: + forward, − reverse) and records the time since the previous pulse. Speed is 1 / pulse interval. Pulses closer than 5 ms are ignored as noise. Only rising edges are counted, because the right wheel's falling edges carry false pulses.
- **PI speed controller.**
  - Feed-forward from a measured effort curve, plus proportional and integral terms on the speed error (`KP 0.25`, `KI 1.0`).
  - A wheel with more drag automatically gets more effort.
  - Effort is clamped to **6–32**. **32 is the fuse cap**: never raise it; higher stall currents blew fuses.
- **Start push.** Until a wheel's first pulse (up to 0.6 s), its effort is at least **24**, to break floor friction.
- **Stuck-wheel kick.** If a driving wheel misses its pulses (1.5 expected intervals, at least 0.3 s), it gets effort 24 for up to 0.4 s.
- **Wheel synchronisation** (`synchronise()`).
  - While both wheels drive the same way, the real distance each has covered since the command changed must keep the commanded ratio (1 on a straight line).
  - The behind wheel is sped up and the other slowed, by up to 0.03 m/s.
  - In simulation, a wheel at its power limit ended 1 count from the other with sync, 21 without.
- **Direction change.** The wheel coasts down (up to 1.5 s), then its driver is **switched off**, the F/R line is set, and the driver is switched on again 0.3 s later. The left driver doesn't reliably follow a direction change while enabled.
- **Stall cut** (`wheelFrozen()`, fuse protection).
  - Trigger: a driven wheel with effort ≥ 12 and no pulse for 3 expected intervals (at least 0.5 s), after a 1 s start-up grace for that wheel.
  - Action: **both** wheels stop for 10 s, then the Mega retries as a fresh start.
- **Safety rules.**
  - The wheels are never driven in opposite directions.
  - A one-wheel command becomes an arc (the other wheel at 45 %).
  - No command for 300 ms means motors off.
  - The brakes are always released (stopping is a coast).

**Key settings at the top of the file:**

- pin numbers;
- `LEFT_INVERTED` / `RIGHT_INVERTED` (direction polarity);
- `PWM_MAX` (fuse cap);
- the speed-control gains;
- stall timings.

**Flash:** `./setup.sh --flash` (stop the robot first: `./start.sh stop`).

**Tests:** `arduino/test/run_tests.sh` compiles the sketch against a mock Arduino (`Arduino.h`). It runs 42 tests (`test_firmware.cpp`) with simulated wheels that have load, lag, friction, jams and noise: speed tracking, drag compensation, arcs, sync, reversals, re-key, stalls, kicks, timeouts, bench mode, the pin map.

### 9.3 `src/wheel_odometry/wheel_odometry/base_controller.py`: Mega link and odometry

A ROS 2 node, started by `real_robot.launch.py`:

- **`/cmd_vel` → wheel speeds** (`wheel_speeds()`).
  - Turn rate is limited so the inner wheel keeps at least ~36 % of the outer (radius ≥ 0.46 m).
  - Turning on the spot becomes a forward arc at 0.08 m/s.
  - Wheel speeds are capped at **0.15 m/s**, keeping the left/right ratio.
  - The wheels are never driven in opposite directions.
- **Easing** (`ease()`). Wheel speeds change at 0.10 m/s² up and 0.30 m/s² down.
- **Serial link.**
  - Opens the Mega without resetting it (DTR held low).
  - Waits for it to boot, then sends `K:` (pulse sizes from `odometry.yaml`).
  - Sends `VL/VR` at 50 Hz.
  - Reconnects by itself if the USB drops, and re-sends `K:` if the Mega restarts.
- **Odometry** (`_on_counts()`, `integrate()`).
  - Signed counts × metres per pulse give each wheel's distance.
  - The exact arc update gives the new pose.
  - Published as `/odom` and the `odom → base_footprint` transform, with measured speed.
  - No guessing between reports.
- **Logs.** The Mega status line once a second; stall messages.

Parameters (from `src/hospital_bringup/config/odometry.yaml` and the launch file): `arduino_port`, `wheel_base` (0.4318 m), `distance_per_pulse`, `right_encoder_multiplier`.

Tests: `src/wheel_odometry/test/test_base_controller_math.py` (9 tests: arc limits, no opposite wheels, easing, arc odometry).

`teleop_keyboard.py` is a simple keyboard driver. `./start.sh map` uses the standard `teleop_twist_keyboard` instead.

### 9.4 `src/hospital_delivery/hospital_delivery/voice_delivery_node.py`: voice control

**Microphone** (`_listen_loop()`):

- **Bluetooth headset.** Audio comes from `scripts/hfp_mic.py` through `/tmp/hospital_hfp_mic.sock`. It's used while the bridge reports audio flowing (`/tmp/hospital_hfp_mic.up`).
- **Otherwise the system microphone** through PipeWire (`arecord`). Switches automatically both ways.
- If audio falls more than 1 s behind (busy Pi), old audio is dropped, so "stop" is never late.

**Speech gate** (`_consume_audio()`):

- Only audio above the room's noise floor is fed to the recognizer.
- **0.5 s before** speech starts and **0.8 s after** it drops are fed too, so a phrase's soft start and its pauses aren't cut.

**Recognizer** (`_new_recognizer()`):

- Vosk, limited to the command phrases of the rooms on the loaded map (`ROOM_ALIASES`).
- Reports per-word confidence.

**Accepting a command** (`_queue_command()`, `_handle_command()`):

- **"stop"** acts on the first partial guess; a false stop is harmless. It cancels **all** Nav2 goals through the action's cancel service (`stop_robot()`), even if the goal handle was lost, and publishes zero speed.
- **Room commands** need a **finished** phrase. Every word must have confidence **≥ 0.4** (parameter `min_confidence`), and the phrase must be complete ("room one", "go to room one", "go home"; not a bare "one" or "home").
- Phrases with unrecognised sound (`[unk]`) are ignored, unless "room \<n\>" or "go home" was heard clearly.
- The same phrase within 3 s is ignored.

**Goal** (`navigate_to_room()`):

- Position comes from the map file's `# room:` lines.
- Heading is the bearing from the robot's current position, so it arrives driving straight in.
- A new goal replaces the old one (Nav2 preempts).
- `_on_nav_result()` logs "Arrived at …", "ABORTED" or "cancelled".

**Other details:**

- `/voice_command` (`std_msgs/String`) feeds typed text into the same path.
- Speech output uses Google TTS, then espeak, if installed.

Parameters: `map_yaml` (set by `start.sh`), `min_confidence` (0.4), `mic_watchdog_s` (0 = off).

### 9.5 Other `hospital_delivery` files

| File | What it does |
|---|---|
| `room_config.py` | `ROOM_ALIASES`: the spoken forms of each room. `rooms_from_map()`: reads `# room:` lines. `goal_yaw()`: heading towards a room. `room_heading()`: alternative "face the centre" heading, currently unused. `ROOM_COORDS`: fallback rooms. |
| `room_markers.py` | Publishes `/room_markers` for RViz: a zone, pin and name per room; highlights the room at the end of the planned path. |
| `rviz/hospital_nav.rviz` | RViz layout: map, scan, robot model, TF, rooms, planned path, stop zone |

### 9.6 `scripts/hfp_mic.py`: Bluetooth headset bridge

Acts as the "phone" (hands-free audio gateway) for any paired headset. PipeWire's own handling made headsets drop the call link before any audio flowed.

- Picks the connected hands-free headset, or tries each paired one; the last one that worked goes first (`~/.hospital_headset`).
- Opens the control link (RFCOMM) and answers the headset's AT commands.
- Opens the audio link (SCO) with **mSBC** (wideband, decoded with libsbc) or **CVSD** (narrowband).
- Publishes 16 kHz audio on the socket, and creates `/tmp/hospital_hfp_mic.up` while audio flows.

### 9.7 `src/hospital_bringup/`: launch files and settings

| File | What it does |
|---|---|
| `launch/real_robot.launch.py` | Robot model (robot_state_publisher), fixed `map → odom` at home (drawn maps), `base_controller` with `odometry.yaml`, lidar driver |
| `launch/localization.launch.py` | Map server, plus AMCL for scanned maps |
| `launch/navigation.launch.py` | All Nav2 servers in **one** process (`component_container_isolated`), managed by a lifecycle manager. Separate processes hung at startup on this Pi. |
| `launch/full_system.launch.py` | Old combined launch, **not used** |
| `config/odometry.yaml` | Wheel calibration ([section 8](#8-calibration)) |
| `config/nav2_params.yaml` | All Nav2 settings, summarised below |
| `config/slam_params.yaml` | slam_toolbox settings for `./start.sh map` |
| `behavior_trees/navigate_to_pose.xml` | Plan → follow → on failure: clear costmaps / wait, retry (30 times, ~2–3 min). Replans every 3 s. No back-up or spin recovery. |

**`nav2_params.yaml`, the important settings:**

| Section | Setting | Value | Why |
|---|---|---|---|
| `planner_server` | `SmacPlannerHybrid`, `DUBIN` | Forward-only arcs | Reversing changes wheel direction, which the left driver doesn't reliably follow |
| | `minimum_turning_radius` | 0.50 m | `base_controller` allows ~0.46 m |
| `controller_server` | RPP `desired_linear_vel` | 0.15 m/s | Real speed (calibrated) |
| | `allow_reversing` | false | Forward-only |
| | `xy_goal_tolerance` | 0.25 m | Tighter tolerances made the robot loop round for another try |
| | `failure_tolerance` | 3 s | Brief blockage doesn't abort |
| | `use_collision_detection` | true | Won't drive a path into an obstacle |
| `velocity_smoother` | `min_velocity` | 0 | Navigation never reverses |
| Both costmaps | `footprint` | ±0.31 × ±0.23 m | The 2 × 1.5 ft body |
| | `inflation_radius` | 0.60 m | Safe distance from walls and obstacles |
| | `obstacle_layer` | lidar, `inf_is_valid: true` | Detours around live obstacles; marks clear when they leave |
| `collision_monitor` | `PolygonStop` | 0.32–0.70 m ahead / 0.32–0.65 m behind | Hard stop |
| | `PolygonSlow` | 0.70–1.10 m ahead, ×0.7 | Slowdown |
| | `base_shift_correction` | false | Late TF on a busy Pi made it stop for "invalid source" |

### 9.8 `start.sh`

| Command | What it does |
|---|---|
| `./start.sh` | Stops leftovers. Starts the robot (base, lidar, map, Nav2, RViz, headset bridge, voice, room markers). Checks health and restarts once if needed. |
| `./start.sh stop` | Stops everything (force-kills stuck nodes, clears stale shared memory) |
| `./start.sh status` | Lists running parts |
| `./start.sh map` | Scans a new map with keyboard driving, then lets you pick rooms |
| `./start.sh savemap [name]` | Saves the map being scanned |
| `./start.sh calibrate` | Wheel-distance calibration ([section 8](#8-calibration)) |

The map is chosen in this order:

1. `maps/floor_map.yaml` (if a scan exists);
2. `maps/open_floor.yaml`;
3. `maps/area_30x40.yaml`.

Override with `MAP=maps/x.yaml ./start.sh`.

---

## 10. Tests and test tools

**Without the robot moving:**

| Command | Checks |
|---|---|
| `arduino/test/run_tests.sh` | 42 firmware tests (simulated wheels) |
| `cd src/wheel_odometry && python3 -m pytest -q test/test_base_controller_math.py` | 9 base-controller tests |
| `python3 scripts/plan_check.py` | Plans every room pair: length, reverses, turn radius, distance to walls |
| `python3 scripts/health_check.py` | The startup checks, on demand |

**Wheels lifted, or a clear floor** (these move the robot; stay at the battery switch):

| Command | Checks |
|---|---|
| `python3 scripts/wheel_speed_test.py` | Commanded vs measured speed: straight, slow, arcs, reverse, stop time |
| `python3 scripts/e2e_test.py [N]` | N random trials through the whole chain (typed commands → Nav2 → wheels): trips, stops, redirects, noise phrases |
| `python3 scripts/floor_tour.py` | Every room from home and back, with outcome, time, stops and stalls per leg; stops at the area boundary |

**Bench tools** (stack stopped with `./start.sh stop`):

| Command | Checks |
|---|---|
| `wheel_direction_test.py` | Each wheel alone at its "forward" level: must roll forward |
| `direction_level_test.py` | Each wheel with F/R LOW and HIGH: must turn both ways |
| `brake_level_test.py` | Each wheel with BRK LOW and HIGH: LOW must release |
| `drive_test.py`, `phase_check.py`, `bench_matrix.py`, `encoder_check.py`, `brake_test.py`, `avi_sweep.py` | Older bench checks (see the README) |
| `direction_check.py`, `pivot_check.py` | Lidar-based direction checks. Need a room with walls in range. |

**Map tools:** `make_area_map.py` (draw a map with rooms), `render_map.py` (map picture), `pick_rooms.py` (click rooms on a scanned map).

---

## 11. Troubleshooting

| Symptom | Likely cause | What to do |
|---|---|---|
| Robot doesn't move; `base.log` shows `STALL HARD STOP` and `L=0` or `R=0` | A driver is latched (red LED) or unpowered, or a speed wire is loose | Battery off for 10 s, then on. Check fuses, LEDs, and the D2/D3 wires. Use `brake_level_test.py` to test each wheel alone. |
| Robot spins on the spot | A wheel runs backwards | `wheel_direction_test.py`. Flip the `*_INVERTED` setting for that wheel and reflash. |
| Drives too far or too short | Calibration off | [Section 8](#8-calibration) |
| Curves on a straight line | Right signal noise or calibration | Check the D3 wire; re-measure both wheels |
| Voice: nothing happens | No mic: `voice.log` says "No microphone yet" | Connect the headset (turn off phone Bluetooth), or plug in a USB mic |
| Voice: "Ignoring unsure phrase" | Unclear speech or noise | Speak closer and clearly. Lower `min_confidence` if needed (0.3–0.4). |
| Voice: "Ignoring short phrase" | Bare "one" / "home" | Say "room one" / "go home" |
| Goal fails with "no valid path" | The robot is near an edge, or something blocks the room | Move it back to home and restart. Clear the area. |
| Robot keeps stopping | Something within 0.7 m ahead, often the person watching | Stand outside the area |
| `Obstacle stop: PROBLEM` at start | Nav2 startup hang | `start.sh` restarts once by itself; otherwise run `./start.sh stop; ./start.sh` |
| `Lidar view: NOTE` | Nothing within 12 m (open floor) | Normal. If there *are* things around, check the lidar is uncovered and level. |
| Mega disappears from USB | Motor noise | Battery off, reseat the Mega on another USB port, `./start.sh` |
| Fuse blows | A wheel stalled under effort | Find the jam. Never raise `PWM_MAX` (32). |

---

## 12. Known limits and next steps

| Limit | Detail | Next step |
|---|---|---|
| **Position from the wheels only** | On an empty floor the lidar sees nothing within 12 m, so there's no correction. Expect ±10–25 cm at a room, growing with distance driven. | Put landmarks (boxes, panels) around the area, or work in a room with walls, and scan it with `./start.sh map`. AMCL then corrects the position continuously. |
| **Coarse wheel pulses** | ~12–13 pulses per wheel turn = 36 mm steps; a one-pulse difference is about 5° of heading | Wheel encoders with more counts per turn would improve odometry and low-speed control a lot |
| **Right speed signal noise** | False pulses on its falling edges (hence rising edges only) | Check the D3 wire: shielded or twisted with ground, away from the phase wires; add a small capacitor to ground |
| **Left driver** | Sometimes latches (wheel held, 0 pulses); doesn't follow direction changes made soon after running | Battery off/on clears it. If it keeps happening, check that driver's wiring and fuse, or replace it. |
| **Forward-only driving** | Can't back away from a wall; rooms must stay ~1.2–1.3 m from the centre in a 20 × 20 ft area | Once the left driver is fixed, reversing could be re-enabled (Reeds-Shepp planner, BackUp recovery). The firmware already handles direction changes safely. |
| **No speaker** | Replies only in the log | USB speaker or sound card |
| **Speech model** | Small Vosk model; headset audio is narrowband | A larger Vosk model or a better microphone improves recognition |

### Versions

| Name | What |
|---|---|
| Branch `floor-tested-v1` | This version (drive, voice, obstacles) |
| Tag `floor-tested-v1` | The first floor-tested drive and voice commit |
| `main` | The older version, before this work |

To restore a version: `git checkout floor-tested-v1`.

Always re-run `./setup.sh --flash` after checking out a version with different firmware.

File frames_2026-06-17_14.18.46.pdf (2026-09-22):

view_frames Result

Recorded at time: 1781686126.4121716

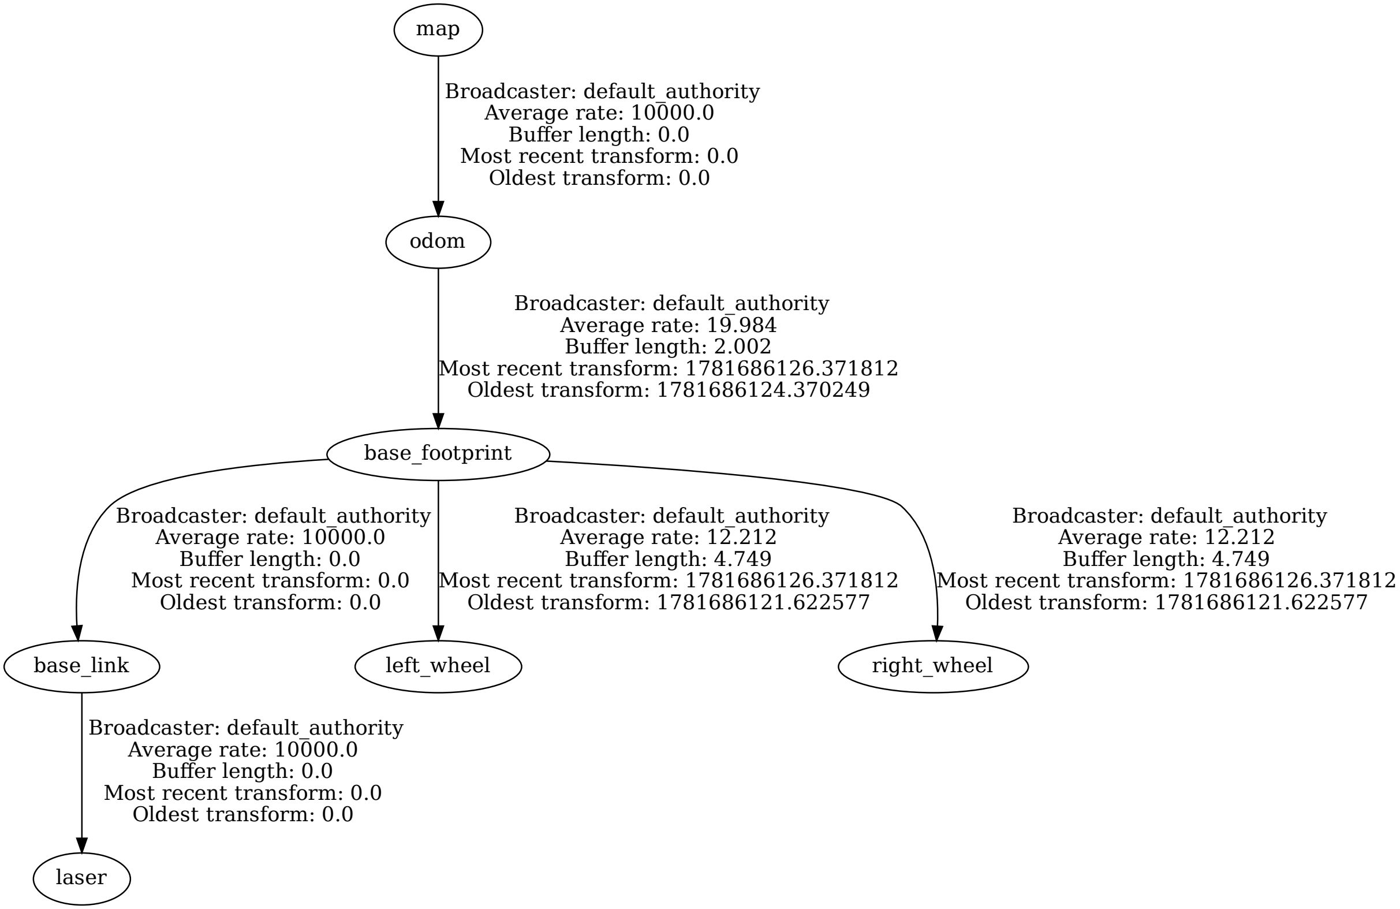
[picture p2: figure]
map; odom; Broadcaster: default_authority Average rate: 10000.0 Buffer length: 0.0 Most recent transform: 0.0 Oldest transform: 0.0; base_footprint; Broadcaster: default_authority Average rate: 19.984 Buffer length: 2.002 Most recent transform: 1781686126.371812 Oldest transform: 1781686124.370249; base_link; left_wheel; Broadcaster: default_authority Average rate: 12.212 Buffer length: 4.749 Most recent transform: 1781686126.371812 Oldest transform: 1781686121.622577; right_wheel; laser

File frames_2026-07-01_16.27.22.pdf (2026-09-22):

view_frames Result

Recorded at time: 1782903442.4842415

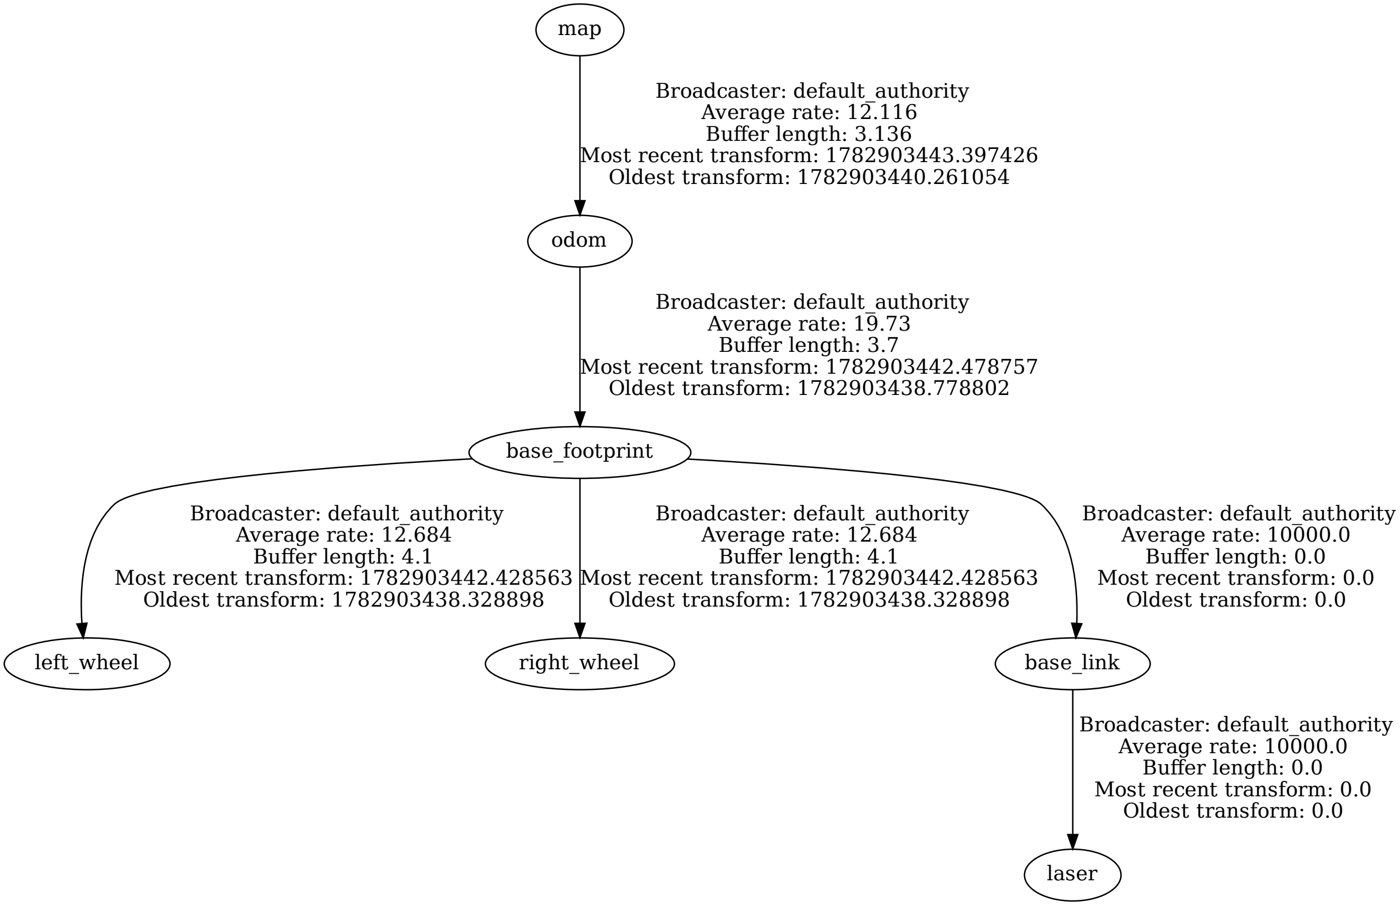
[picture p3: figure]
base_footprint; left_wheel; Broadcaster: default_authority Average rate: 12.684 Buffer length: 4.1 Most recent transform: 1782903442.428563 Oldest transform: 1782903438.328898; right_wheel; base_link; Broadcaster: default_authority Average rate: 10000.0 Buffer length: 0.0 Most recent transform: 0.0 Oldest transform: 0.0; odom; Broadcaster: default_authority Average rate: 19.73 Buffer length: 3.7 Most recent transform: 1782903442.478757 Oldest transform: 1782903438.778802; laser; map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

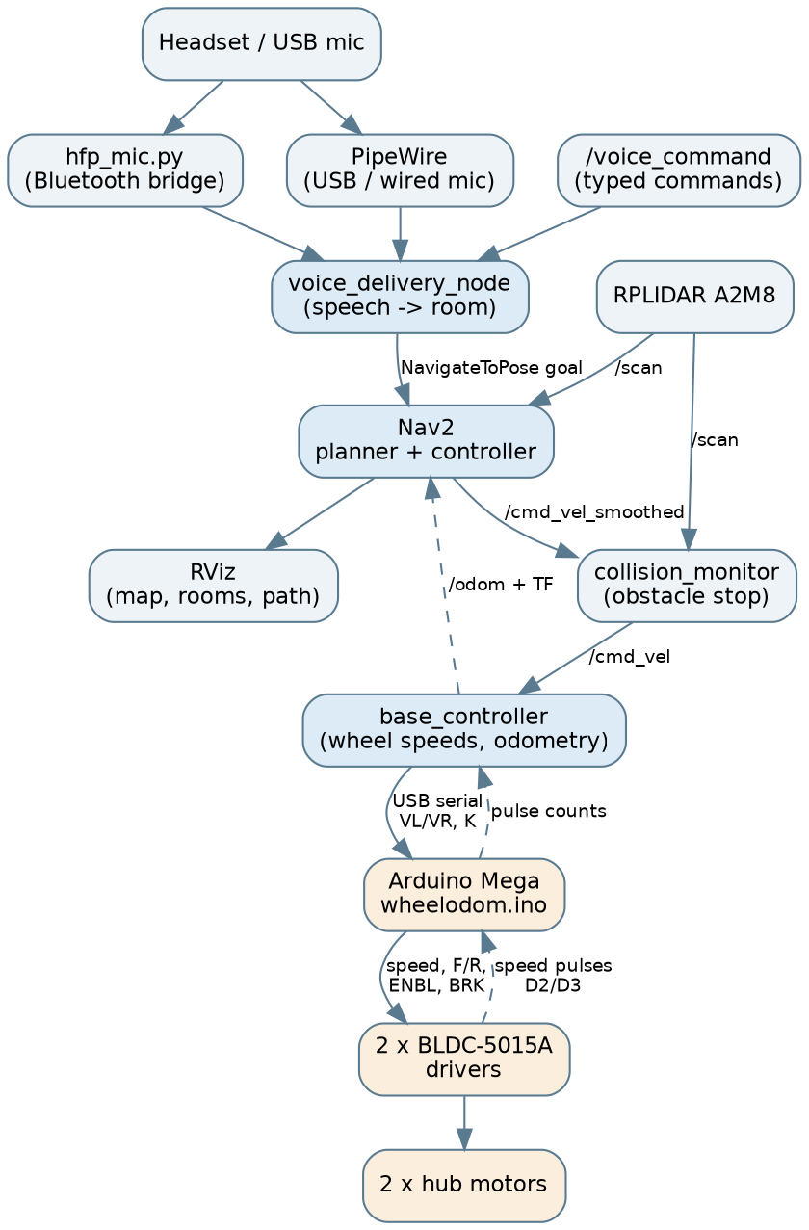
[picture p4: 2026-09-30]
docs/architecture.png

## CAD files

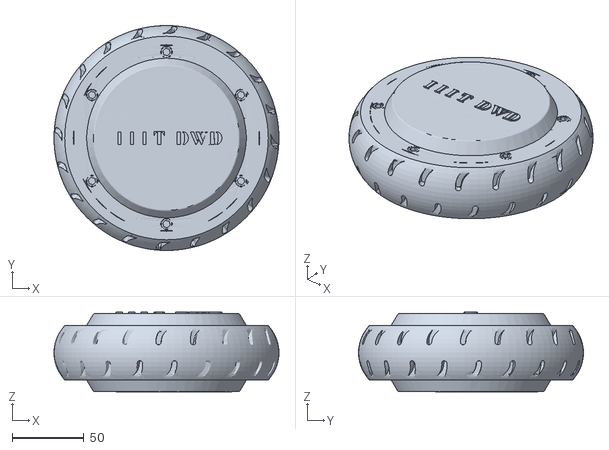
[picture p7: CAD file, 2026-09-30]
src/hospital_description/meshes/left_wheel.stl
157.1 x 157.1 x 55.5

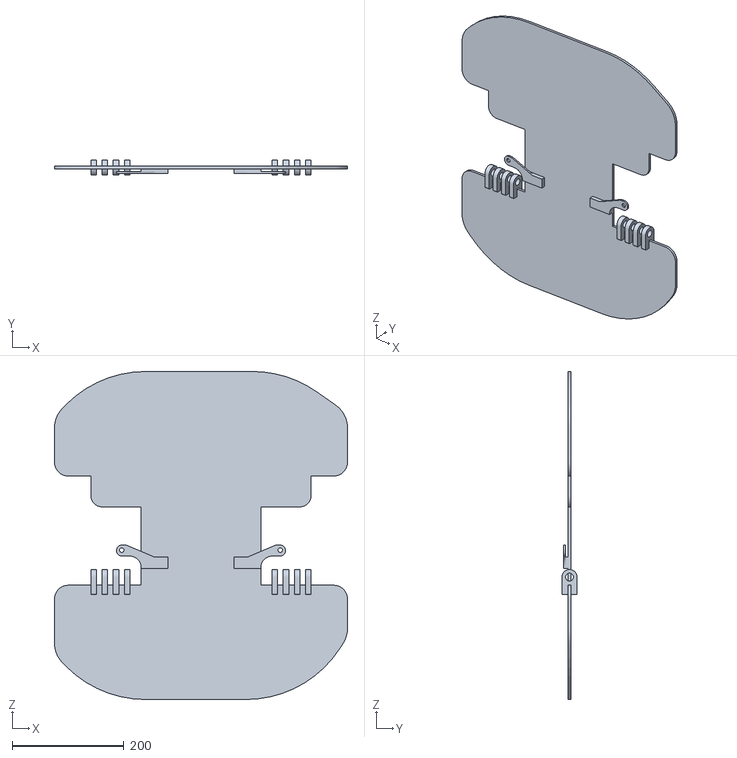
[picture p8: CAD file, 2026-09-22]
src/hospital_description/meshes/base.stl
524.0 x 27.0 x 586.3

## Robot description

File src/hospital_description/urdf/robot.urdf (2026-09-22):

<?xml version="1.0"?>
<!--
  Differential-drive hospital bot.

  Dimensions (must stay in sync with base_controller):
    wheel_radius = 0.0762 m
    wheel_base   = 0.4318 m  (left y=+0.2159, right y=-0.2159)

  Nav2 uses robot_base_frame:=base_footprint and robot_radius≈0.22
  (circle approx of this footprint). Collision boxes below are for
  RViz / future footprint publishers — Nav2 currently uses the radius.
-->
<robot name="hospital_bot">

  <!-- Ground / odom child frame (published by base_controller) -->
  <link name="base_footprint"/>

  <!-- Chassis: raised to wheel axle height -->
  <link name="base_link">
    <visual>
      <!--
        CAD origin is at a corner.
        X/Y shift centers the mesh; Z centers height on the axle.
      -->
      <origin xyz="-0.293165 -0.26707 -0.0127" rpy="1.57079632679 0 1.57079632679"/>
      <geometry>
        <mesh filename="package://hospital_description/meshes/base.stl" scale="0.001 0.001 0.001"/>
      </geometry>
      <material name="grey">
        <color rgba="0.6 0.6 0.6 1"/>
      </material>
    </visual>
    <!-- Approx chassis for collision / footprint sanity (L x W x H) -->
    <collision>
      <origin xyz="0 0 0.05" rpy="0 0 0"/>
      <geometry>
        <box size="0.50 0.40 0.20"/>
      </geometry>
    </collision>
  </link>

  <joint name="base_footprint_to_base_link" type="fixed">
    <parent link="base_footprint"/>
    <child link="base_link"/>
    <!-- Axle height = wheel radius -->
    <origin xyz="0 0 0.0762" rpy="0 0 0"/>
  </joint>

  <!-- LEFT WHEEL -->
  <link name="left_wheel">
    <visual>
      <origin xyz="0.0762 0 0.0762" rpy="0 1.5708 1.5708"/>
      <geometry>
        <mesh filename="package://hospital_description/meshes/left_wheel.stl" scale="0.001 0.001 0.001"/>
      </geometry>
    </visual>
    <collision>
      <origin xyz="0 0 0.0762" rpy="1.5708 0 0"/>
      <geometry>
        <cylinder radius="0.0762" length="0.04"/>
      </geometry>
    </collision>
  </link>

  <joint name="left_wheel_joint" type="continuous">
    <parent link="base_footprint"/>
    <child link="left_wheel"/>
    <origin xyz="0 0.2159 0" rpy="0 0 0"/>
    <axis xyz="0 -1 0"/>
  </joint>

  <!-- RIGHT WHEEL -->
  <link name="right_wheel">
    <visual>
      <!-- Same STL as left, mirrored by rotation -->
      <origin xyz="-0.0762 0 0.0762" rpy="0 1.5708 4.7124"/>
      <geometry>
        <mesh filename="package://hospital_description/meshes/left_wheel.stl" scale="0.001 0.001 0.001"/>
      </geometry>
    </visual>
    <collision>
      <origin xyz="0 0 0.0762" rpy="1.5708 0 0"/>
      <geometry>
        <cylinder radius="0.0762" length="0.04"/>
      </geometry>
    </collision>
  </link>

  <joint name="right_wheel_joint" type="continuous">
    <parent link="base_footprint"/>
    <child link="right_wheel"/>
    <origin xyz="0 -0.2159 0" rpy="0 0 0"/>
    <axis xyz="0 -1 0"/>
  </joint>

  <!-- RPLIDAR A2M8 — frame_id must match rplidar launch (laser) -->
  <link name="laser">
    <visual>
      <origin xyz="0 0 0" rpy="0 0 0"/>
      <geometry>
        <cylinder radius="0.035" length="0.04"/>
      </geometry>
      <material name="black">
        <color rgba="0 0 0 1"/>
      </material>
    </visual>
    <collision>
      <origin xyz="0 0 0" rpy="0 0 0"/>
      <geometry>
        <cylinder radius="0.035" length="0.04"/>
      </geometry>
    </collision>
  </link>

  <joint name="base_link_to_laser" type="fixed">
    <parent link="base_link"/>
    <child link="laser"/>
    <!-- ~15 cm above chassis center → ~22.6 cm above ground -->
    <origin xyz="0 0 0.15" rpy="0 0 0"/>
  </joint>

</robot>

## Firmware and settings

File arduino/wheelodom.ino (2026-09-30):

// Mega firmware: two BLDC-5015A hub drivers with closed-loop wheel speed.
//
// Protocol
//   Host -> "VL:<m/s> VR:<m/s>\n"   wheel speeds; must repeat within 300 ms
//           "K:<left> [<right>]\n"  metres per speed pulse per wheel (host
//                                   sends its calibrated values at connect)
//           "PINS ..." / "PINS OFF" bench pin control (wheels lifted only)
//   Mega -> "SAFE START READY"
//           "L:<count> R:<count>"   every 50 ms: SIGNED pulse counts. The
//                                   driver pulses carry no direction, so each
//                                   pulse counts in the direction the wheel is
//                                   driven; F/R only flips once it has stopped,
//                                   so coasting pulses keep the old sign.
//           "S: pwmL=.. pwmR=.. enblL=.. enblR=.. brkL=.. brkR=.. brkOff=..
//               L=.. R=.. spL=.. spR=.. tgL=.. tgR=.."  while driving
//               (sp = measured, tg = target wheel speed, pulses/s)
//           "STALL HARD STOP"       a driven wheel gave no pulses: both cut
//           "K OK <left> <right>"
//
// Speed control: each wheel's speed is measured from the interval between
// its driver's speed pulses, and a PI loop sets the effort so the wheel turns
// at the commanded speed whatever its load. Open-loop effort let a wheel with
// more drag fall behind, so straight lines curved and Nav2 steered the robot
// in circles (floor, 2026-09-30).
//
// Fuse safety (unchanged rules): effort never above PWM_MAX; a driven wheel
// that stops pulsing cuts BOTH wheels for FAULT_COOLDOWN_MS; no host command
// for CMD_TIMEOUT_MS = motors off; wheels never driven in opposite directions;
// a direction change coasts to a stop first.
//
// Bench 2026-09-30: the yellow wire (D52/D53) is the driver's direction input
// and the blue wire (D30/D31) its brake (LOW = released). The purple speed
// wires are crossed: D10 feeds the D22/D30/D2 driver.
//
// Bench mode (wheels lifted): "PINS [L|R] B<0|1> E<0|1> F<0|1> A<effort>"
// holds raw BRK/ENBL/F-R levels and the speed input (capped at PWM_MAX) on one
// side or both; "W<0-255>" writes a raw speed byte (no cap, calibration
// only). "PINS OFF", any VL/VR command, or PIN_TEST_MS clears it.

// ================== PINS ==================
#define L_AVI   10   // purple (crossed: drives the D22/D30/D2 driver)
#define L_FR    52   // yellow
#define L_ENBL  22   // red
#define L_BRK   30   // blue
#define R_AVI   9    // purple (crossed: drives the D23/D31/D3 driver)
#define R_FR    53   // yellow
#define R_ENBL  23   // red
#define R_BRK   31   // blue
#define ENC_LEFT   2   // driver speed pulses, rising edges
#define ENC_RIGHT  3

// Hubs face opposite ways: the same wheel direction needs opposite F/R.
// Floor 2026-09-30: with this setting a straight run from rest went
// straight (1.6 m); with RIGHT_INVERTED true even a pure forward run spun.
// The spinning seen with this setting came from direction CHANGES the left
// driver didn't follow: hence the re-key below and forward-only navigation.
#define LEFT_INVERTED   true
#define RIGHT_INVERTED  false
const bool FR_OPEN_DRAIN = false;

// Mega HIGH = ENBL run; Mega LOW = brake released.
const bool INVERT_ENBL_BRK = true;
const bool ENBL_RUN  = INVERT_ENBL_BRK ? HIGH : LOW;
const bool ENBL_STOP = INVERT_ENBL_BRK ? LOW  : HIGH;
const bool BRK_RELEASE = INVERT_ENBL_BRK ? LOW : HIGH;
const bool L_BRK_RELEASE = BRK_RELEASE;
const bool R_BRK_RELEASE = BRK_RELEASE;

// ================== SPEED CONTROL ==================
const float VEL_DEADBAND = 0.01;      // m/s; below = wheel stopped
const float MAX_WHEEL_MPS = 0.20;     // command clamp
const float DEFAULT_M_PER_PULSE = 0.0402;   // measured on the floor 2026-09-30 (host sends its own)
// Feed-forward from the lifted-wheel curve (2026-09-30): pulses/s ~
// 2.3 * (effort - 5). Load needs more effort; the integrator adds it.
const float FF_ZERO_EFFORT = 5.0;
const float FF_PPS_PER_EFFORT = 2.3;
const float KP = 0.25;                // effort per pulse/s of error
const float KI = 1.0;                 // effort per (pulse/s * s)
const float INTEG_MAX = 25.0;
const float EFFORT_SLEW = 120.0;      // effort units per second, up and down
const unsigned long CONTROL_MS = 20;

const int PWM_START = 6;              // lowest effort for a driven wheel (lifted: ~2 pulses/s)
const int PWM_MAX = 32;               // fuse cap (stall current at ~40 blew fuses)
const int PWM_BREAKAWAY = 24;         // until a wheel's first pulse: 16 didn't start a wheel on the floor, 28 lurched
const unsigned long BREAKAWAY_MS = 600;     // floor: 300 ms didn't start a slow wheel
// Stuck-wheel kick: a driven wheel that misses its pulses (no pulse for 1.5
// expected gaps, >= 300 ms) gets breakaway effort for up to KICK_MS. Floor
// friction stopped a slow inner wheel (~2.5 pulses/s at effort 7) and the
// PI loop was too slow to free it before the stall cut (2026-09-30).
const unsigned long KICK_MS = 400;

const unsigned long PULSE_DEBOUNCE_US = 5000;  // real pulses >= 60 ms apart at our speeds
// Direction change: coast with effort 0 until the wheel is (nearly) still,
// or for at most REVERSE_COAST_MS (a lifted wheel spins down slowly), then
// switch THAT driver off, set F/R, and switch it on again REKEY_MS later.
// The left driver doesn't reliably follow an F/R change while enabled soon
// after running: the wheel kept turning the old way and the robot spun on
// the spot (floor 2026-09-30). A disabled driver takes the new direction.
const float REVERSE_FLIP_PPS = 1.5;
const unsigned long REVERSE_COAST_MS = 1500;
const unsigned long REKEY_MS = 300;
const unsigned long SPEED_TIMEOUT_US = 500000; // no pulse for 0.5 s = 0 speed

// Wheel synchronisation: while both wheels drive the same way, the real
// distance each has covered since the command last changed must keep the
// commanded ratio (1 = straight). The behind wheel is sped up and the other
// slowed by SYNC_GAIN m/s per metre of difference, at most SYNC_MAX. The
// per-wheel speed loop alone let start-up and drag differences add up, and
// the robot drifted off a straight line.
const float SYNC_GAIN = 1.0;
const float SYNC_MAX = 0.03;

const unsigned long CMD_TIMEOUT_MS = 300;
const unsigned long IDLE_ENBL_OFF_MS = 250;
const unsigned long REPORT_MS = 50;

// Stall cut: a driven wheel (effort >= STALL_PWM_MIN) with no pulse for
// STALL_CUT_MS, once STALL_GRACE_MS have passed since THAT wheel started
// (from rest, a reversal or a fault), cuts both wheels. Per wheel: a wheel
// reversing mid-drive restarts from rest and needs the grace too.
const unsigned long STALL_CUT_MS = 500;
const unsigned long STALL_GRACE_MS = 1000;   // floor: reversing from rest > 0.7 s
const int STALL_PWM_MIN = 12;
const unsigned long FAULT_COOLDOWN_MS = 10000;
// Bench mode must be refreshed like VL/VR: a stalled host left a wheel running
// for a whole minute on the floor (2026-09-30). Repeat the PINS command.
const unsigned long PIN_TEST_MS = 1500;

struct Wheel {
  int avi, fr, enbl, brk;
  bool inverted;
  bool brk_release;
  int side;                          // 0 = left, 1 = right
  volatile long count;
  volatile unsigned long last_us;    // time of the last counted pulse
  volatile unsigned long period_us;  // mean interval between edges
  volatile unsigned long last_gap_us;
  float effort;
  float integ;
  float target_pps;
  bool dir_fwd;
  bool driving;                      // driven (not stopped / coasting)
  bool pulsed_since_start;
  unsigned long start_ms;            // when this wheel last started driving
  unsigned long coast_since_ms;      // effort reached 0 while waiting to reverse
  unsigned long rekey_until_ms;      // driver off after a direction change until
  unsigned long kick_until_ms;       // stuck-wheel kick running until
  long stall_count;
  unsigned long stall_since_ms;
};

Wheel L = {L_AVI, L_FR, L_ENBL, L_BRK, LEFT_INVERTED, L_BRK_RELEASE, 0, 0, 0, 0, 0,
           0, 0, 0, true, false, false, 0, 0, 0, 0, 0, 0};
Wheel R = {R_AVI, R_FR, R_ENBL, R_BRK, RIGHT_INVERTED, R_BRK_RELEASE, 1, 0, 0, 0, 0,
           0, 0, 0, true, false, false, 0, 0, 0, 0, 0, 0};

float m_per_pulse[2] = {DEFAULT_M_PER_PULSE, DEFAULT_M_PER_PULSE};
float vl_target = 0.0;
float vr_target = 0.0;
bool command_seen = false;
bool motors_enabled = false;
unsigned long last_cmd_ms = 0;
unsigned long last_control_ms = 0;
unsigned long fully_stopped_since_ms = 0;
unsigned long fault_until_ms = 0;
String cmdBuffer = "";
bool sync_on = false;
float sync_ratio = 0.0;
long sync_l0 = 0, sync_r0 = 0;

// Bench pin test, per side [0]=left [1]=right; -1 = not overridden.
int pin_test_brk[2] = {-1, -1};
int pin_test_enbl[2] = {-1, -1};
int pin_test_fr[2] = {-1, -1};
int pin_test_avi[2] = {-1, -1};
int pin_test_raw[2] = {-1, -1};
bool pin_test_on = false;
unsigned long pin_test_until_ms = 0;

// ================== PULSES ==================
void countPulse(Wheel& w) {
  unsigned long now = micros();
  unsigned long gap = now - w.last_us;
  if (w.last_us != 0 && gap < PULSE_DEBOUNCE_US) return;   // electrical noise
  // Speed: the mean of the last two gaps (smooths pulse-to-pulse jitter).
  if (w.last_us != 0) {
    w.period_us = w.last_gap_us ? (gap + w.last_gap_us) / 2 : gap;
    w.last_gap_us = gap;
  }
  w.last_us = now;
  w.count += w.dir_fwd ? 1 : -1;
}
void encLeftIsr()  { countPulse(L); }
void encRightIsr() { countPulse(R); }

long readCount(Wheel& w) {
  noInterrupts();
  long c = w.count;
  interrupts();
  return c;
}

// Measured wheel speed in pulses/s (no direction). Between pulses the speed
// can only be lower than 1/(time since the last pulse), so a slowing wheel
// reads lower at once instead of holding its last value.
float measuredPps(Wheel& w) {
  noInterrupts();
  unsigned long last = w.last_us;
  unsigned long period = w.period_us;
  interrupts();
  if (last == 0 || period == 0) return 0.0;
  unsigned long since = micros() - last;
  if (since > SPEED_TIMEOUT_US) return 0.0;
  unsigned long p = since > period ? since : period;
  return 1e6 / (float)p;
}

// ================== OUTPUTS ==================
int aviByte(float effort) {
  return constrain((int)(effort + 0.5), 0, 255);
}

void writeAvi(int pin, float effort) {
  analogWrite(pin, aviByte(effort));
}

void writeFR(int pin, bool level) {
  if (FR_OPEN_DRAIN && level == HIGH) {
    pinMode(pin, INPUT);
  } else {
    digitalWrite(pin, level);
    pinMode(pin, OUTPUT);
  }
}

void setDir(Wheel& w, bool fwd) {
  w.dir_fwd = fwd;
  writeFR(w.fr, fwd == w.inverted ? LOW : HIGH);
}

void releaseBrake() {
  // Never leave the hubs locked.
  digitalWrite(L_BRK, L_BRK_RELEASE);
  digitalWrite(R_BRK, R_BRK_RELEASE);
}

void resetControl(Wheel& w) {
  w.effort = 0.0;
  w.integ = 0.0;
  w.target_pps = 0.0;
  w.driving = false;
  w.rekey_until_ms = 0;
  w.kick_until_ms = 0;
}

// Speed inputs to 0, drivers disabled, brakes released (coast).
void hardStop() {
  writeAvi(L_AVI, 0);
  writeAvi(R_AVI, 0);
  releaseBrake();
  digitalWrite(L_ENBL, ENBL_STOP);
  digitalWrite(R_ENBL, ENBL_STOP);
  motors_enabled = false;
  resetControl(L);
  resetControl(R);
}

void enterFault(const char* msg) {
  hardStop();
  fault_until_ms = millis() + FAULT_COOLDOWN_MS;
  Serial.println(msg);
}

void motorEnable() {
  releaseBrake();
  if (!motors_enabled) {
    // A stop->run edge with the speed input at 0 clears the drivers' latch.
    digitalWrite(L_ENBL, ENBL_STOP);
    digitalWrite(R_ENBL, ENBL_STOP);
    delay(40);
    writeAvi(L_AVI, 0);
    writeAvi(R_AVI, 0);
    delay(10);
    digitalWrite(L_ENBL, ENBL_RUN);
    delayMicroseconds(5000);
    digitalWrite(R_ENBL, ENBL_RUN);
    motors_enabled = true;
  }
}

// ================== BENCH PIN TEST ==================
void clearPinTest() {
  for (int i = 0; i < 2; i++) {
    pin_test_brk[i] = pin_test_enbl[i] = pin_test_fr[i] = pin_test_avi[i] = -1;
    pin_test_raw[i] = -1;
  }
  pin_test_on = false;
}

bool pinTestActive() {
  if (!pin_test_on) return false;
  if (millis() >= pin_test_until_ms) {
    clearPinTest();
    Serial.println("PINS OFF (timeout)");
    return false;
  }
  return true;
}

void applyPinTest() {
  Wheel* ws[2] = {&L, &R};
  for (int i = 0; i < 2; i++) {
    Wheel& w = *ws[i];
    if (pin_test_brk[i] >= 0) digitalWrite(w.brk, pin_test_brk[i] ? HIGH : LOW);
    if (pin_test_enbl[i] >= 0) digitalWrite(w.enbl, pin_test_enbl[i] ? HIGH : LOW);
    if (pin_test_fr[i] >= 0) writeFR(w.fr, pin_test_fr[i] ? HIGH : LOW);
    int effort = pin_test_avi[i] > 0 ? min(pin_test_avi[i], PWM_MAX) : 0;
    if (pin_test_raw[i] >= 0) {
      analogWrite(w.avi, pin_test_raw[i]);
      w.effort = pin_test_raw[i];
    } else {
      writeAvi(w.avi, effort);
      w.effort = effort;
    }
  }
}

// Value after " <key>" in cmd, or -1.
int pinArg(const String& cmd, const char* key) {
  int k = cmd.indexOf(key);
  if (k < 0) return -1;
  int v = 0;
  bool any = false;
  for (unsigned int n = k + 2; n < cmd.length(); n++) {
    char c = cmd[n];
    if (c < '0' || c > '9') break;
    v = v * 10 + (c - '0');
    any = true;
  }
  return any ? v : -1;
}

// ================== DRIVE ==================
float slewToward(float current, float target, float dt) {
  float step = EFFORT_SLEW * dt;
  if (target > current) return min(current + step, target);
  return max(current - step, target);
}

// One control step for one wheel. vel: signed m/s (0 = stop this wheel).
void controlWheel(Wheel& w, float vel, float dt, unsigned long now_ms) {
  bool stop = fabs(vel) < VEL_DEADBAND;
  bool fwd = vel >= 0.0;
  // Coast down before changing direction: F/R never flips under effort.
  bool must_coast = false;
  if (!stop && fwd != w.dir_fwd) {
    if (w.effort > 1.0) {
      w.coast_since_ms = 0;
      must_coast = true;
    } else {
      if (w.coast_since_ms == 0) w.coast_since_ms = now_ms;
      must_coast = measuredPps(w) > REVERSE_FLIP_PPS &&
                   now_ms - w.coast_since_ms < REVERSE_COAST_MS;
    }
  }
  if (stop || must_coast) {
    w.integ = 0.0;
    w.target_pps = 0.0;
    w.driving = false;
    w.effort = slewToward(w.effort, 0.0, dt);
    return;
  }
  w.coast_since_ms = 0;
  if (fwd != w.dir_fwd) {
    // Re-key: driver off, new direction, back on after REKEY_MS.
    digitalWrite(w.enbl, ENBL_STOP);
    setDir(w, fwd);
    w.rekey_until_ms = now_ms + REKEY_MS;
  }
  if (w.rekey_until_ms != 0) {
    w.effort = 0.0;
    w.integ = 0.0;
    w.target_pps = 0.0;
    w.driving = false;
    if (now_ms < w.rekey_until_ms) return;
    w.rekey_until_ms = 0;
    digitalWrite(w.enbl, ENBL_RUN);
  }
  if (!w.driving) {
    // A fresh start for this wheel: stall grace and breakaway from now.
    w.driving = true;
    w.start_ms = now_ms;
    w.stall_count = readCount(w);
    w.stall_since_ms = now_ms;
    w.pulsed_since_start = false;
    w.kick_until_ms = 0;
  }

  w.target_pps = fabs(vel) / m_per_pulse[w.side];
  float meas = measuredPps(w);
  float err = w.target_pps - meas;
  float ff = FF_ZERO_EFFORT + w.target_pps / FF_PPS_PER_EFFORT;
  float integ = constrain(w.integ + KI * err * dt, -INTEG_MAX, INTEG_MAX);
  float u = ff + KP * err + integ;
  // Anti-windup: don't integrate further into a limit.
  if ((u > PWM_MAX && err > 0) || (u < PWM_START && err < 0)) {
    integ = w.integ;
    u = ff + KP * err + integ;
  }
  w.integ = integ;
  if (!w.pulsed_since_start && now_ms - w.start_ms < BREAKAWAY_MS) {
    u = max(u, (float)PWM_BREAKAWAY);   // get a loaded wheel rolling
  }
  // Stuck-wheel kick (after the start-up breakaway).
  unsigned long gap = (unsigned long)max(300.0, 1500.0 / max(w.target_pps, 0.1f));
  if (w.pulsed_since_start && w.kick_until_ms == 0 && now_ms - w.stall_since_ms > gap) {
    w.kick_until_ms = now_ms + KICK_MS;
  }
  if (w.kick_until_ms != 0) {
    if (now_ms < w.kick_until_ms && now_ms - w.stall_since_ms > gap) {
      u = max(u, (float)PWM_BREAKAWAY);
    } else if (now_ms - w.stall_since_ms <= gap) {
      w.kick_until_ms = 0;              // it moved: ready for the next kick
    }
  }
  u = constrain(u, (float)PWM_START, (float)PWM_MAX);
  w.effort = slewToward(w.effort, u, dt);
}

// Stall check for one wheel: true = driven with no pulse for STALL_CUT_MS.
bool wheelFrozen(Wheel& w, unsigned long now_ms) {
  long c = readCount(w);
  if (c != w.stall_count) {
    w.stall_count = c;
    w.stall_since_ms = now_ms;
    if (w.driving) w.pulsed_since_start = true;
    return false;
  }
  // Slow wheels pulse rarely (an inner wheel in a turn: ~1.6 pulses/s), so
  // "frozen" = no pulse for 3 expected gaps, never less than STALL_CUT_MS.
  unsigned long cut = STALL_CUT_MS;
  if (w.target_pps > 0.1) cut = max(cut, (unsigned long)(3000.0 / w.target_pps));
  cut = max(cut, (unsigned long)(300 + KICK_MS + 300));   // the kick gets its chance
  return w.driving && w.effort >= STALL_PWM_MIN &&
         now_ms - w.start_ms >= STALL_GRACE_MS &&
         now_ms - w.stall_since_ms >= cut;
}

// Adjust the two wheel speeds so their real distances keep the commanded
// ratio (see SYNC_GAIN). Restarts whenever the ratio or direction changes.
void synchronise(float& leftVel, float& rightVel) {
  bool same_way = fabs(leftVel) >= VEL_DEADBAND && fabs(rightVel) >= VEL_DEADBAND &&
                  leftVel * rightVel > 0.0 && L.dir_fwd == (leftVel > 0.0) &&
                  R.dir_fwd == (rightVel > 0.0);
  if (!same_way) {
    sync_on = false;
    return;
  }
  float ratio = rightVel / leftVel;
  if (!sync_on || fabs(ratio - sync_ratio) > 0.05 * sync_ratio + 0.02) {
    sync_on = true;
    sync_ratio = ratio;
    sync_l0 = readCount(L);
    sync_r0 = readCount(R);
    return;
  }
  float dl = (readCount(L) - sync_l0) * m_per_pulse[0];   // signed metres
  float dr = (readCount(R) - sync_r0) * m_per_pulse[1];
  float corr = constrain(SYNC_GAIN * (dl * ratio - dr), -SYNC_MAX, SYNC_MAX);
  // corr > 0: the right wheel is behind (in either direction of travel).
  float nl = leftVel - corr / 2.0, nr = rightVel + corr / 2.0;
  // Never stop or reverse a wheel by synchronising.
  if (nl * leftVel > 0.0 && fabs(nl) >= VEL_DEADBAND) leftVel = nl;
  if (nr * rightVel > 0.0 && fabs(nr) >= VEL_DEADBAND) rightVel = nr;
}

void driveMotors(float leftVel, float rightVel) {
  unsigned long now_ms = millis();
  if (fault_until_ms != 0) {
    if (now_ms < fault_until_ms) {
      hardStop();
      return;
    }
    fault_until_ms = 0;   // hardStop() cleared 'driving': the retry is a fresh start
  }
  if (now_ms - last_control_ms < CONTROL_MS) return;
  float dt = last_control_ms == 0 ? CONTROL_MS / 1000.0
                                  : (now_ms - last_control_ms) / 1000.0;
  if (dt > 0.2) dt = CONTROL_MS / 1000.0;
  last_control_ms = now_ms;

  leftVel = constrain(leftVel, -MAX_WHEEL_MPS, MAX_WHEEL_MPS);
  rightVel = constrain(rightVel, -MAX_WHEEL_MPS, MAX_WHEEL_MPS);
  // Never drive the wheels in opposite directions (the hubs fight, fuses blow):
  // both take the stronger command's direction and size.
  if (fabs(leftVel) >= VEL_DEADBAND && fabs(rightVel) >= VEL_DEADBAND &&
      leftVel * rightVel < 0.0) {
    float v = fabs(rightVel) >= fabs(leftVel) ? rightVel : leftVel;
    leftVel = rightVel = v;
  }
  // Never pivot on one stopped hub: a one-wheel command becomes an arc.
  if (fabs(leftVel) >= VEL_DEADBAND && fabs(rightVel) < VEL_DEADBAND) {
    rightVel = leftVel * 0.45;
  } else if (fabs(rightVel) >= VEL_DEADBAND && fabs(leftVel) < VEL_DEADBAND) {
    leftVel = rightVel * 0.45;
  }
  bool moving = fabs(leftVel) >= VEL_DEADBAND || fabs(rightVel) >= VEL_DEADBAND;

  if (!moving) {
    sync_on = false;
    controlWheel(L, 0.0, dt, now_ms);
    controlWheel(R, 0.0, dt, now_ms);
    writeAvi(L_AVI, L.effort);
    writeAvi(R_AVI, R.effort);
    if (L.effort < 1.0 && R.effort < 1.0) {
      if (fully_stopped_since_ms == 0) fully_stopped_since_ms = now_ms;
      if (motors_enabled && now_ms - fully_stopped_since_ms >= IDLE_ENBL_OFF_MS) {
        hardStop();
      }
    }
    return;
  }
  fully_stopped_since_ms = 0;

  // Set F/R before the ENBL edge so a driver never sees it change enabled.
  if (!motors_enabled) {
    if (fabs(leftVel) >= VEL_DEADBAND) setDir(L, leftVel >= 0.0);
    if (fabs(rightVel) >= VEL_DEADBAND) setDir(R, rightVel >= 0.0);
    delayMicroseconds(2000);
  }
  motorEnable();
  synchronise(leftVel, rightVel);
  controlWheel(L, leftVel, dt, now_ms);
  controlWheel(R, rightVel, dt, now_ms);

  bool l_frozen = wheelFrozen(L, now_ms);
  bool r_frozen = wheelFrozen(R, now_ms);
  if (l_frozen || r_frozen) {
    enterFault("STALL HARD STOP");
    return;
  }
  writeAvi(L_AVI, L.effort);
  writeAvi(R_AVI, R.effort);
}

// ================== REPORTS ==================
void printEncoders() {
  Serial.print("L:");
  Serial.print(readCount(L));
  Serial.print(" R:");
  Serial.println(readCount(R));
}
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
void loop() {
  while (Serial.available()) {
    char c = (char)Serial.read();
    if (c == '\n') {
      if (cmdBuffer.length() > 0) parseCommand(cmdBuffer);
      cmdBuffer = "";
    } else if (c != '\r') {
      cmdBuffer += c;
      if (cmdBuffer.length() > 64) cmdBuffer = "";
    }
  }

  bool host_alive = command_seen && millis() - last_cmd_ms <= CMD_TIMEOUT_MS;
  if (!host_alive) {
    command_seen = false;
    vl_target = vr_target = 0.0;
  }
  if (pinTestActive()) {
    applyPinTest();
  } else if (host_alive) {
    driveMotors(vl_target, vr_target);
  } else if (motors_enabled || L.effort > 0.0 || R.effort > 0.0) {
    hardStop();   // no host = motors dead, at once
  }

  static unsigned long last_report = 0;
  if (millis() - last_report >= REPORT_MS) {
    last_report = millis();
    printEncoders();
    if (pin_test_on || motors_enabled) printStatus();
  }
}

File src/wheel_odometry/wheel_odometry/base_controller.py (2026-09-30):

#!/usr/bin/env python3
"""Base controller: /cmd_vel -> Mega wheel speeds, Mega pulses -> /odom + TF.

The Mega (arduino/wheelodom.ino) closes the speed loop on each wheel, so a
commanded wheel speed is the real one whatever the drag. This node:

  * turns /cmd_vel into left/right wheel speeds for an arcs-only base (no
    turning on the spot, wheels never in opposite directions) and eases them
    in (acceleration limit);
  * sends them as "VL:<m/s> VR:<m/s>" at 50 Hz while moving (the Mega stops
    by itself 300 ms after the last command);
  * sends the calibrated metres-per-pulse of each wheel ("K:<l> <r>") at
    every (re)connect, from config/odometry.yaml;
  * integrates the Mega's signed pulse counts into /odom and odom->base_footprint.
    The pose comes from measured wheel motion only: no extrapolation between
    reports, no command-based guessing.
"""

import math
import time
import termios

import rclpy
import serial
from geometry_msgs.msg import Quaternion, TransformStamped, Twist
from nav_msgs.msg import Odometry
from rclpy.executors import ExternalShutdownException
from rclpy.node import Node
from sensor_msgs.msg import JointState
from tf2_ros import TransformBroadcaster

MAX_WHEEL_MPS = 0.15     # cruise (real m/s since the floor calibration)
WHEEL_DEADBAND = 0.008   # m/s; below = wheel stopped
# Tightest arc: radius ~0.46 m, the inner wheel at ~36 % of the outer one.
# Tighter scrubs the tyres and stalls a hub; wider left no room to turn
# round in a 20 x 20 ft area (the planner uses 0.50 m).
MAX_TURN_RATE_PER_SPEED = 0.47   # w <= v / (wheel_base / 2) * this
MIN_ARC_SPEED = 0.08     # pure rotation becomes a forward arc at this speed
ACCEL = 0.10             # m/s^2 per wheel, speeding up
DECEL = 0.30             # m/s^2 per wheel, slowing down
CMD_TIMEOUT = 0.5        # s without /cmd_vel -> stop
BOOT_TIME = 1.8          # s after opening the port (the Mega may reset)
RETRY_PERIOD = 0.5       # s between reconnect attempts
STATUS_LOG_PERIOD = 1.0  # s between logged Mega status lines
MAX_PULSES_PER_REPORT = 60   # 50 ms reports; more = corrupt line


def wheel_speeds(v, w, wheel_base):
    """(left, right) wheel speeds in m/s for body speed v and turn rate w."""
    half = wheel_base / 2.0
    if abs(w) > 0.015 and abs(v) < MIN_ARC_SPEED:
        v = math.copysign(MIN_ARC_SPEED, v if v != 0.0 else 1.0)
    if abs(v) >= 0.02:
        w_max = abs(v) / half * MAX_TURN_RATE_PER_SPEED
        w = max(-w_max, min(w_max, w))
    left, right = v - half * w, v + half * w
    # Keep the ratio when limiting the faster wheel to cruise.
    peak = max(abs(left), abs(right))
    if peak > MAX_WHEEL_MPS:
        left, right = left * MAX_WHEEL_MPS / peak, right * MAX_WHEEL_MPS / peak
    if abs(left) < WHEEL_DEADBAND:
        left = 0.0
    if abs(right) < WHEEL_DEADBAND:
        right = 0.0
    if left * right < 0.0:            # never opposite directions
        left = right = left if abs(left) >= abs(right) else right
    return left, right


def ease(current, target, dt):
    """Move a wheel speed toward target within the accel/decel limits."""
    limit = (DECEL if abs(target) < abs(current) or target * current < 0 else ACCEL) * dt
    return current + max(-limit, min(limit, target - current))


def integrate(x, y, theta, dl, dr, wheel_base):
    """Pose after the wheels moved dl, dr metres (exact for an arc)."""
    ds = 0.5 * (dl + dr)
    dth = (dr - dl) / wheel_base
    if abs(dth) < 1e-6:
        return x + ds * math.cos(theta), y + ds * math.sin(theta), theta
    r = ds / dth
    return (x + r * (math.sin(theta + dth) - math.sin(theta)),
            y - r * (math.cos(theta + dth) - math.cos(theta)),
            theta + dth)


class BaseController(Node):
    def __init__(self):
        super().__init__('base_controller')
        self.declare_parameter('arduino_port', '/dev/arduino')
        self.declare_parameter('wheel_base', 0.4318)
        # Metres per speed pulse of the left wheel, and right/left pulse
        # length. From config/odometry.yaml (scripts/floor_calibrate.py).
        self.declare_parameter('distance_per_pulse', 0.0025)
        self.declare_parameter('right_encoder_multiplier', 1.0)
        self.wheel_base = self.get_parameter('wheel_base').value
        self.k_left = self.get_parameter('distance_per_pulse').value
        self.k_right = self.k_left * self.get_parameter('right_encoder_multiplier').value

        self.odom_pub = self.create_publisher(Odometry, '/odom', 10)
        self.joint_pub = self.create_publisher(JointState, '/joint_states', 10)
        self.tf_broadcaster = TransformBroadcaster(self)
        self.create_subscription(Twist, '/cmd_vel', self._on_cmd_vel, 10)

        self.ser = None
        self.booted = False
        self.ready_at = 0.0
        self.next_attempt = 0.0
        self.rx_buf = b''

        self.target = [0.0, 0.0]      # commanded wheel speeds (m/s)
        self.wheel = [0.0, 0.0]       # eased wheel speeds sent to the Mega
        self.last_cmd = 0.0
        self.last_tick = time.monotonic()

        self.x = self.y = self.theta = 0.0
        self.counts = None            # last (left, right) signed counts
        self.v_meas = self.w_meas = 0.0
        self.last_report = None
        self.wheel_angle = [0.0, 0.0]
        self.wheel_radius = 0.0762
        self._last_status_log = 0.0

        self.create_timer(0.02, self._tick)
        self.get_logger().info(
            f'Base controller: {self.k_left * 1000:.3f} / {self.k_right * 1000:.3f} '
            'mm per pulse (left / right)')

    # ---------------- commands ----------------
    def _on_cmd_vel(self, msg):
        self.target = list(wheel_speeds(msg.linear.x, msg.angular.z, self.wheel_base))
        self.last_cmd = time.monotonic()

    def _tick(self):
        now = time.monotonic()
        dt = min(max(now - self.last_tick, 0.0), 0.1)
        self.last_tick = now
        if now - self.last_cmd > CMD_TIMEOUT:
            self.target = [0.0, 0.0]
        for i in (0, 1):
            self.wheel[i] = ease(self.wheel[i], self.target[i], dt)
            if abs(self.wheel[i]) < 0.002 and self.target[i] == 0.0:
                self.wheel[i] = 0.0

        self._service_link()
        if self.booted and (any(self.wheel) or now - self.last_cmd < CMD_TIMEOUT):
            self._send(f'VL:{self.wheel[0]:.3f} VR:{self.wheel[1]:.3f}')
        self._publish_joints(dt)

    # ---------------- serial link ----------------
    def _open(self, port):
        """Open the Mega without the DTR pulse that resets it."""
        link = serial.Serial()
        link.port = port
        link.baudrate = 115200
        link.timeout = 0
        link.write_timeout = 0.1
        link.dtr = False
        link.rts = False
        link.open()
        return link
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

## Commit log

2026-09-22 Harden real-robot bringup: continuous voice, safer drive, Nav2 without docking.
    Fix URDF launch YAML parse so the robot shows in RViz, keep a single cmd_vel path, stagger straight-drive PWM, and add voice room-matching tests.
    [robot.urdf]
2026-09-22 Initial hospital robot workspace for HUMANOID-BOT.
    Includes ROS 2 bringup, Nav2, voice delivery, wheel odometry, Arduino firmware, and start.sh for the real-robot demo.
    [base.stl, left_wheel.stl, right_wheel.stl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]
2026-09-22 Document motor, encoder, and cable-color wiring in the README.
2026-09-29 Harden start.sh bringup for reliable voice to Nav2 driving.
    Keep map_server and collision_monitor active, sync Nav2/voice/base code on start, clamp encoder odom to the map, and soften Mega stall cuts so room commands drive instead of spinning or aborting off-map.
    [base_controller.py, hfp_mic.py]
2026-09-29 Lower PWM and stop both wheels on stall to protect fuses.
    Breakaway was stuck at 70 with frozen encoders, blowing fuses and spinning in place. Cap PWM at 58 and zero both sides on stall.
    [base_controller.py, wheelodom.ino]
2026-09-30 Floor-tested drive: closed-loop wheels, calibrated odometry, voice control.
    Firmware (arduino/wheelodom.ino):
    - Per-wheel PI speed control from the driver speed pulses, plus wheel
    synchronisation (real distances kept at the commanded ratio).
    - Signed pulse counts, driver re-key on direction change, stuck-wheel kick,
    per-wheel stall grace, bench mode that stops 1.5 s after its last command.
    - 42 host tests (arduino/test/run_tests.sh).
    Base controller: pulse-only odometry, per-wheel pulse sizes measured on the
    floor (36 mm left, right 0.92), cruise 0.15 m/s.
    Navigation: forward-only Hybrid-A* (turn radius 0.5 m), real 2 x 1.5 ft
    footprint, 20 x 20 ft open floor map with home + rooms 1-3,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
    [left_wheel.stl, right_wheel.stl]
2026-09-30 Obstacle detours and waiting, three rooms, more forgiving voice commands.
    - Navigation: live lidar obstacles in the planner (detour at a safe
    distance; beams with no return clear old marks), controller tolerates 3 s
    of blockage, up to 30 wait/replan retries before a trip fails.
    - Map: 20 x 20 ft open floor, home + rooms 1-3 about 1.2-1.3 m out (room
    for forward-only turn-arounds); arrival tolerance 0.25 m.
    - Voice: vocabulary limited to the map's rooms, confidence threshold 0.4,
    a clearly heard "room <n>" / "go home" counts even if the start of the
    phrase was garbled.
    - floor_tour.py tours every room of the map.
    [make_area_map.py]
2026-09-30 Handover docs, setup.sh, requirements.txt and a room map picture.
    - docs/HANDOVER.md: architecture, hardware, wiring with cable colours,
    setup, running, map and rooms, calibration, every file explained, tests,
    troubleshooting, known limits.
    - setup.sh: one-time install (ROS 2 Jazzy packages, audio, speech venv and
    model, arduino-cli), build, optional --test and --flash.
    - requirements.txt: Python packages.
    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
